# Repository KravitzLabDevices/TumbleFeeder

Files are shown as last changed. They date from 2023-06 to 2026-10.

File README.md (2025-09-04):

# TumbleFeeder
This is a feeding device for mice

## Front 


## Back

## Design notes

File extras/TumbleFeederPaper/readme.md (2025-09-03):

The paper using the TumbleFeeder, Barrett et al., Current Biology 2025 is [here](https://www.sciencedirect.com/science/article/pii/S0960982225006839?via%3Dihub)  

Example Code and Data Analysis pipelines are [available here](https://github.com/KravitzLab/Barrett2024/tree/main)

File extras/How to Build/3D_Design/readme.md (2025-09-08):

Print the 3D parts
[Download the four STLs here](https://github.com/KravitzLabDevices/TumbleFeeder/tree/main/How%20to%20Build/3D_Design).  We print in PLA plus with a Bambu Labs X1C, but the exact printer and material are not critical. If you don't have a printer you can even outsource the printing to companies like Shapeways. 
[Editable TinkerCAD file](https://www.tinkercad.com/things/1IhfIT78Xpz-tumble-feeder-sept2024) are here

{AB542B00-AB26-41CA-B7AA-14D2C4CE198B}

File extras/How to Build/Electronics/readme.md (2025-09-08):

# Electronics

First order the two custom PCBs.  You can order from OshPark using the link below, or order from any PCB house using the [Eagle .brd and .sch files](https://github.com/KravitzLabDevices/TumbleFeeder/tree/main/How%20to%20Build/Electronics).
1) The main PCB<br>
6047149a1ac6b429ac75a2f4fb032c3e

<br>
<br>
2) The small touch adapter PCB:  <br>
{D103E9D6-0BA7-4F27-A367-4E5D317DD4B2}  <br>  


Next order all the necessary parts, [the BOM is here](https://docs.google.com/spreadsheets/d/167cMoID8Alf8LLFngqACXI5k8x5zef9LXBQ9bw7NaI0/edit?gid=0#gid=0).  
To assemble the PCB, we recommend watching the [Tumble Feeder Build Video](https://www.youtube.com/watch?v=_t9MZKi8byM") (YouTube Link)

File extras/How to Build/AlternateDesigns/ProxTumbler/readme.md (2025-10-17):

### A variant of the TumbleFeeder that uses the [VL6180](https://www.adafruit.com/product/3316) prox sensor to detect the mouse and open the feeder.



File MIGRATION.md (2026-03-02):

# Migration Guide: Converting CastleCode to TumbleFeeder Library

This guide shows how to convert your existing CastleCode sketch to use the TumbleFeeder library.

## Step 1: Install the Library

Copy the `TumbleFeeder` folder to your Arduino libraries directory.

## Step 2: Update Your Main Sketch Header

### Before (a_header.h):
```cpp
//INCLUDE LIBRARIES
#include <Servo.h>
// ... other includes

/********************************************************
  Initialize variables
********************************************************/
unsigned long rightstart;
unsigned long leftstart;
int currentpos = 0;
int leftPokeCount = 0;
int rightPokeCount = 0;
int leftPokeDur = 0;
int rightPokeDur = 0;
int FeederCount = 0;
int leftFeederDur = 0;
int FR=1;
// ... other variables

/********************************************************
  Initialize servo
********************************************************/
Servo myservo;
```

### After:
```cpp
//INCLUDE LIBRARIES
#include <TumbleFeeder.h>  // Add this
#include <Servo.h>  // Keep if needed elsewhere
// ... other includes

/********************************************************
  Initialize TumbleFeeder
********************************************************/
TumbleFeeder feeder;

/********************************************************
  Keep other variables
********************************************************/
unsigned long menustart;
bool SessionStarted = false;
const unsigned long display_interval = 100;
unsigned long next_interval = 0;
unsigned long open_duration = 60;
int on_hour;
int off_hour;
bool mode = 0;
// ... other non-feeder variables
```

## Step 3: Update Setup() in Main Sketch

### Before (Startup.ino):
```cpp
void setup() {
  // ... RTC, SD, display setup
  
  pinMode(13, OUTPUT);
  // ... other pin setups
  
  attachInterrupt(digitalPinToInterrupt(A2), left_interrupt, FALLING);
  attachInterrupt(digitalPinToInterrupt(A0), right_interrupt, FALLING);
  attachInterrupt(digitalPinToInterrupt(A1), feed_interrupt, FALLING);
}
```

### After:
```cpp
void setup() {
  // ... RTC, SD, display setup (unchanged)
  
  // Initialize feeder
  feeder.begin(closedpos, openpos);  // Use your position values
  feeder.setFR(FR);
  feeder.setOpenDuration(open_duration);
  
  // Register callbacks
  feeder.setLogCallback(logData);
  feeder.setDisplayCallback(update_display);
  
  // Attach interrupts (same as before)
  attachInterrupt(digitalPinToInterrupt(A2), left_interrupt, FALLING);
  attachInterrupt(digitalPinToInterrupt(A0), right_interrupt, FALLING);
  attachInterrupt(digitalPinToInterrupt(A1), feed_interrupt, FALLING);
  
  // ... rest of setup
}
```

## Step 4: Update Interrupt Handlers

### Before (InterruptRoutines.ino):
```cpp
void left_interrupt() {
  left_touch = 1;
}

void right_interrupt() {
  right_touch = 1;
}

void feed_interrupt() {
  feed_touch = 1;
}
```

### After:
```cpp
void left_interrupt() {
  feeder.handleLeftTouch();
}

void right_interrupt() {
  feeder.handleRightTouch();
}

void feed_interrupt() {
  feeder.handleFeederTouch();
}
```

## Step 5: Replace Feeder Functions

### Delete or comment out MoveFeeder.ino
The library now handles all feeder movement. Delete these functions:
- `feeder_open()`
- `feeder_close()`
- `shake()`
- `shake_food()`

If you need them elsewhere, use:
```cpp
feeder.feederOpen();
feeder.feederClose();
feeder.shake();
feeder.shakeFood();
```

## Step 6: Update run() Function

### Before (run.ino):
```cpp
void run() {
  unsigned long current = millis();

  if (current >= next_interval && mode == 0) {
    check_inputs(closedpos, openpos, open_duration);  
    next_interval = current + display_interval;
  }

  else if (current >= next_interval && mode == 1) {
    free_inputs(closedpos, openpos);
    next_interval = current + display_interval;
    if (wake_counter % 180 == 0) {
      shake_food();
    }
  }
}
```

### After:
```cpp
void run() {
  unsigned long current = millis();

  if (current >= next_interval && mode == 0) {
    feeder.checkInputs(open_duration);  // Simplified!
    next_interval = current + display_interval;
  }

  else if (current >= next_interval && mode == 1) {
    feeder.freeInputs();  // Simplified!
    next_interval = current + display_interval;
    if (wake_counter % 180 == 0) {
      feeder.shakeFood();
    }
  }
}
```

## Step 7: Delete Checkinputs.ino

The library handles all input checking. Delete these functions:
- `check_inputs()`
- `checkLeft()`
- `checkRight()`
- `checkFeeder()`
- `free_inputs()`

## Step 8: Update Variable References

Anywhere you access feeder counters, you can use either:

### Option A: Direct access (backward compatible)
```cpp
// Works the same as before
if (feeder.leftPokeCount > 10) {
  // do something
}
```

### Option B: Getter methods (recommended)
```cpp
if (feeder.getLeftPokeCount() > 10) {
  // do something
}
```

## Step 9: Update Display.ino

### Before:
```cpp
void update_display() {
  display.setCursor(0, 0);
  display.print("L:");
  display.print(leftPokeCount);
  display.print(" R:");
  display.print(rightPokeCount);
  display.print(" F:");
  display.print(FeederCount);
  display.refresh();
}
```

### After:
```cpp
void update_display() {
  display.setCursor(0, 0);
  display.print("L:");
  display.print(feeder.leftPokeCount);  // or feeder.getLeftPokeCount()
  display.print(" R:");
  display.print(feeder.rightPokeCount);  // or feeder.getRightPokeCount()
  display.print(" F:");
  display.print(feeder.FeederCount);     // or feeder.getFeederCount()
  display.refresh();
}
```

## Step 10: Update LogData.ino

### Before:
```cpp
void logData() {
  logfile.print(millis());
  logfile.print(",");
  logfile.print(leftPokeCount);
  logfile.print(",");
  logfile.print(rightPokeCount);
  logfile.print(",");
  logfile.print(FeederCount);
  // ... etc
}
```

### After:
```cpp
void logData() {
  logfile.print(millis());
  logfile.print(",");
  logfile.print(feeder.leftPokeCount);
  logfile.print(",");
  logfile.print(feeder.rightPokeCount);
  logfile.print(",");
  logfile.print(feeder.FeederCount);
  // ... etc
}
```

## Complete Conversion Checklist

- [ ] Install TumbleFeeder library
- [ ] Add `#include <TumbleFeeder.h>` to header
- [ ] Create `TumbleFeeder feeder;` object
- [ ] Remove old feeder-related global variables
- [ ] Update `setup()` with `feeder.begin()` and callbacks
- [ ] Update interrupt handlers to call `feeder.handleXXX()`
- [ ] Delete/comment out MoveFeeder.ino
- [ ] Update `run()` to use `feeder.checkInputs()`
- [ ] Delete/comment out Checkinputs.ino
- [ ] Update all variable references to `feeder.variableName`
- [ ] Test on hardware!

## Benefits After Migration

✅ **Cleaner code**: Feeder logic is encapsulated  
✅ **Reusable**: Use the library across multiple projects  
✅ **Maintainable**: Bug fixes in one place  
✅ **Flexible**: Easy to swap between FR schedules  
✅ **Professional**: Standard Arduino library format  

## Troubleshooting

### "Feeder not responding"
- Check servo positions: `feeder.setPositions(0, 150)`
- Verify interrupts are attached correctly
- Check pin connections match hardcoded pins

### "Counts not incrementing"
- Ensure callbacks are registered: `feeder.setLogCallback(logData)`
- Check ISRs are calling `feeder.handleXXX()` methods
- Verify touch sensors are wired correctly (A2, A0, A1)

### "Compile errors"
- Make sure library is in Arduino libraries folder
- Restart Arduino IDE after installing library
- Check you removed duplicate function definitions

## Need Help?

Open an issue on GitHub with:
- Your error message
- Code snippet showing the problem
- What you've already tried

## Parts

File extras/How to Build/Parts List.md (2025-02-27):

## <a href="https://docs.google.com/spreadsheets/d/167cMoID8Alf8LLFngqACXI5k8x5zef9LXBQ9bw7NaI0/edit?usp=sharing" target="_blank" rel="noopener noreferrer">Click here</a> for TumbleFeeder parts list.
<br>
Updated 2/27/2025

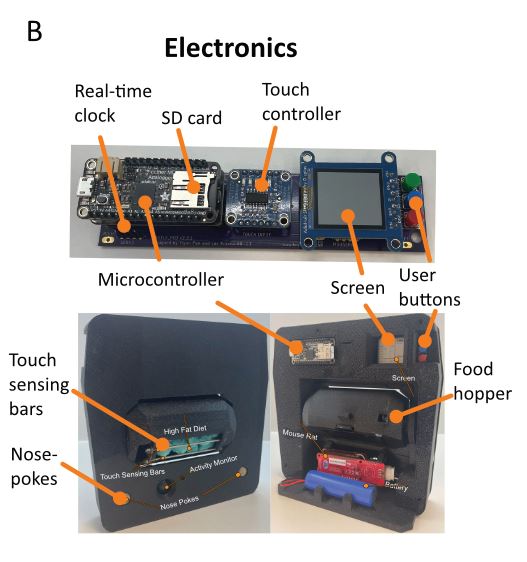
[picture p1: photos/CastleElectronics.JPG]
TumbleFeeder


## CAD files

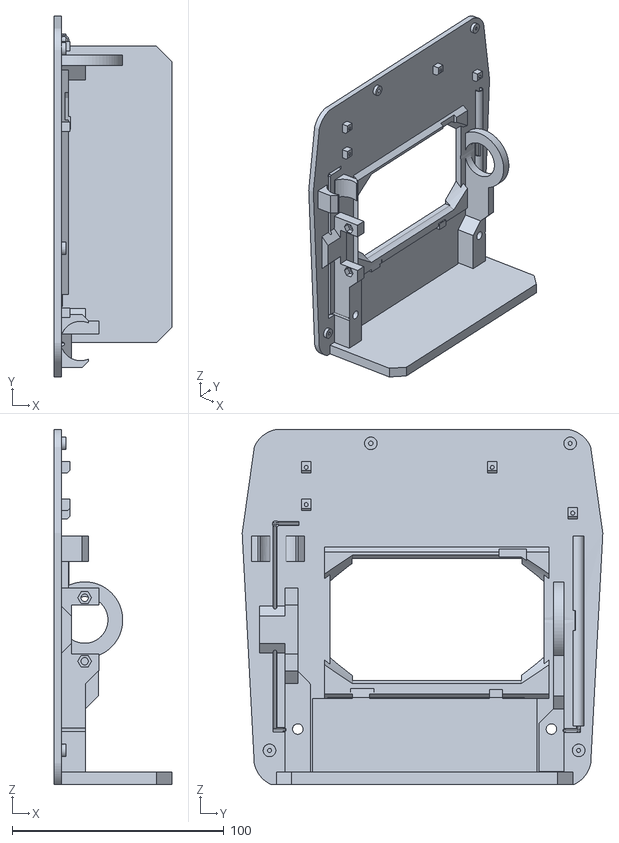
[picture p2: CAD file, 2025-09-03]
extras/How to Build/3D_Design/TumbleFeederFront.stl
55.5 x 170.3 x 167.6

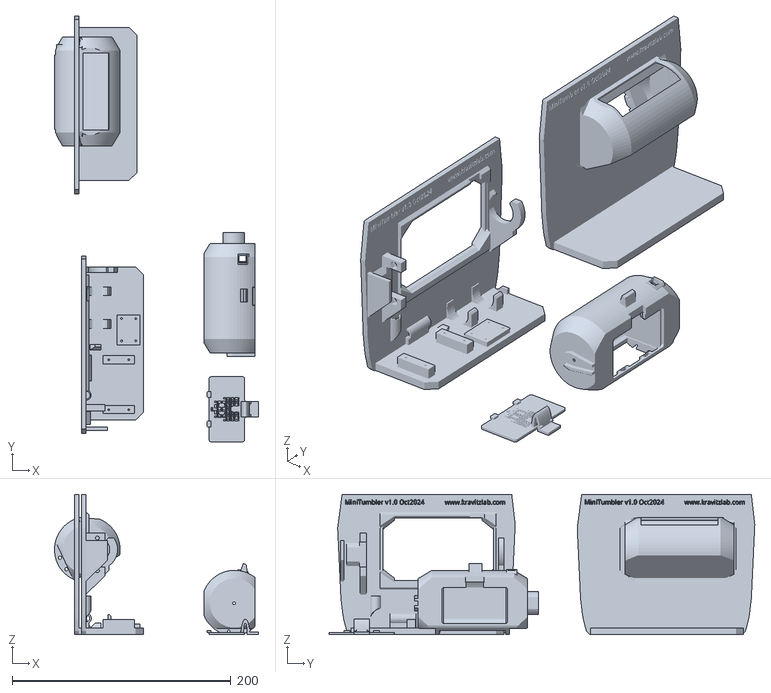
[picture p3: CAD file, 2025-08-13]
extras/How to Build/AlternateDesigns/MiniTumbler/How to build/3D files/Mini Tumbler August2025.stl
186.5 x 389.0 x 128.0

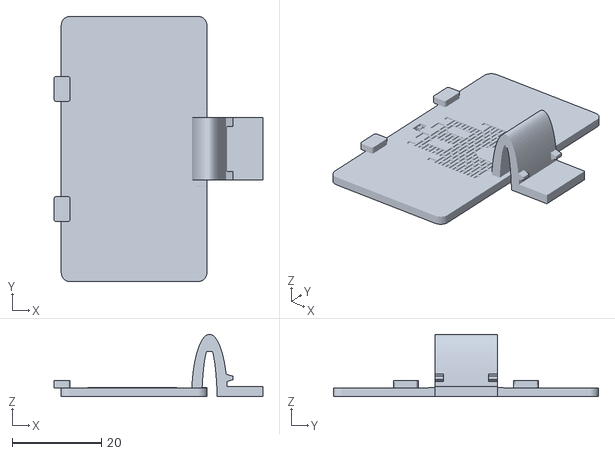
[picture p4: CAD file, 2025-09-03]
extras/How to Build/3D_Design/TumbleFeederDoor.stl
46.9 x 59.5 x 14.0

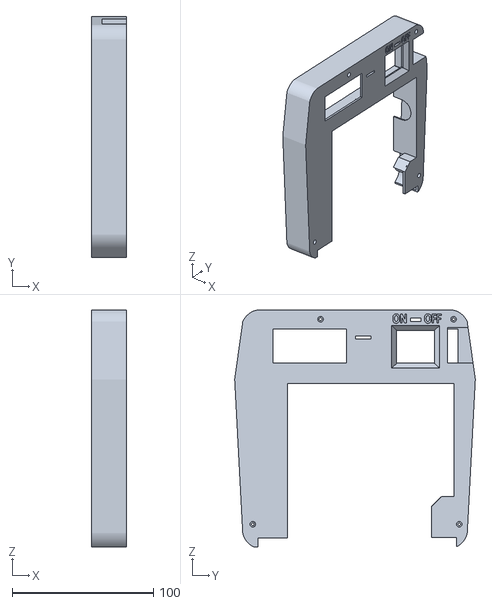
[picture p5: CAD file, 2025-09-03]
extras/How to Build/3D_Design/TumbleFeederBack.stl
25.0 x 170.2 x 167.6

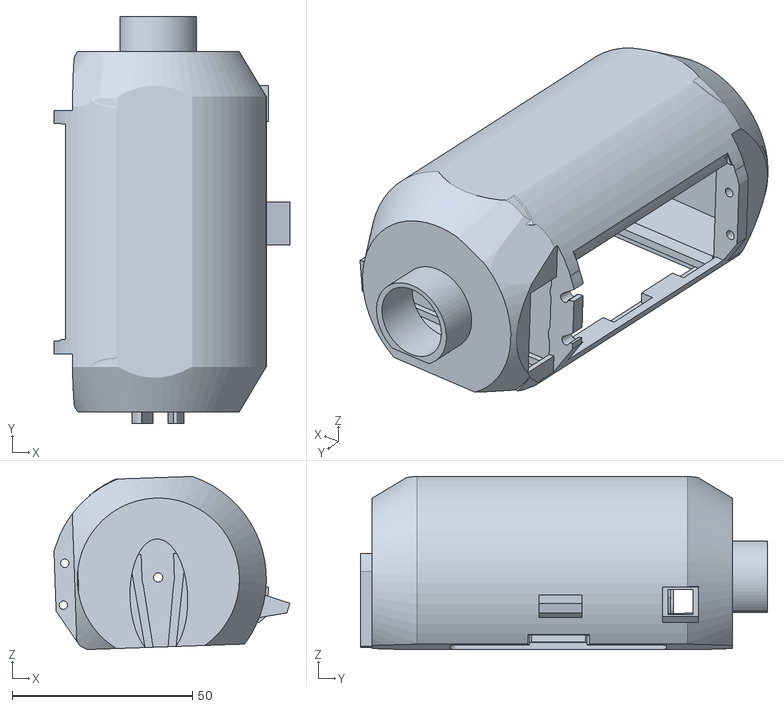
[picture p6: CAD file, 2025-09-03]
extras/How to Build/3D_Design/TumbleFeederHopper.stl
65.5 x 113.1 x 48.1

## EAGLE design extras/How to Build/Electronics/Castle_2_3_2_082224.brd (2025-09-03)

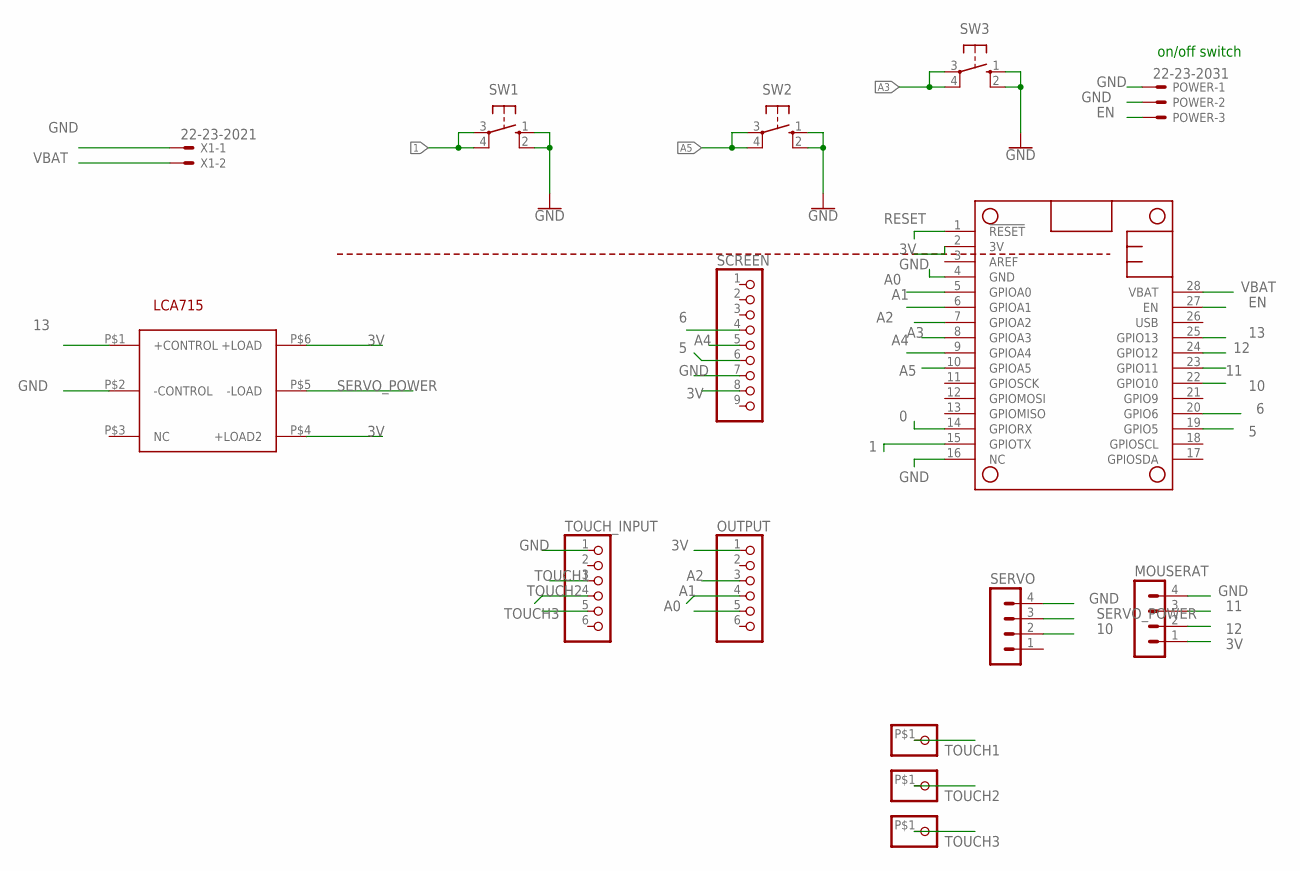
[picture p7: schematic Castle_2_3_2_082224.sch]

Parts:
EXTRAGND, EXTRAGND1, EXTRAGND2: PINHD-1X1-BIGPOGO; 1X1-BIGPOGO
LCA715: LCA715S; LCA7XX
MOUSERAT: MA04-1
MS2: FEATHERWING_NODIM; FEATHERWING_DIM
OUTPUT: PINHD-1X6; 1X06
POWER: 22-23-2031
SCREEN: PINHD-1X9; 1X09-BIG
SERVO: MA04-1
SW1, SW2, SW3: 10-XX; B3F-10XX
TOUCH_INPUT: PINHD-1X6; 1X06
X1: 22-23-2021

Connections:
0: MS2.14 (GPIORX)
1: MS2.15 (GPIOTX), SW1.3, SW1.4 (P1)
3V: LCA715.P$4 (+LOAD2), LCA715.P$6 (+LOAD), MOUSERAT.1, MS2.2 (3V), OUTPUT.1, SCREEN.8
5: MS2.19 (GPIO5), SCREEN.6
6: MS2.20 (GPIO6), SCREEN.4
10: MS2.22 (GPIO10), SERVO.2
11: MOUSERAT.3, MS2.23 (GPIO11)
12: MOUSERAT.2, MS2.24 (GPIO12)
13: LCA715.P$1 (+CONTROL), MS2.25 (GPIO13)
A0: MS2.5 (GPIOA0), OUTPUT.5
A1: MS2.6 (GPIOA1), OUTPUT.4
A2: MS2.7 (GPIOA2), OUTPUT.3
A3: MS2.8 (GPIOA3), SW3.3, SW3.4 (P1)
A4: MS2.9 (GPIOA4), SCREEN.5
A5: MS2.10 (GPIOA5), SW2.3, SW2.4 (P1)
EN: MS2.27 (EN), POWER.3
GND: LCA715.P$2 (-CONTROL), MOUSERAT.4, MS2.4 (GND), MS2.16 (NC), POWER.1, POWER.2, SCREEN.7, SERVO.4, SW1.1 (S), SW1.2 (S1), SW2.1 (S), SW2.2 (S1), SW3.1 (S), SW3.2 (S1), TOUCH_INPUT.1, X1.1
RESET: MS2.1 (!RESET)
SERVO_POWER: LCA715.P$5 (-LOAD), SERVO.3
TOUCH1: EXTRAGND.P$1, TOUCH_INPUT.3
TOUCH2: EXTRAGND1.P$1, TOUCH_INPUT.4
TOUCH3: EXTRAGND2.P$1, TOUCH_INPUT.5
VBAT: MS2.28 (VBAT), X1.2

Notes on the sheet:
on/off switch

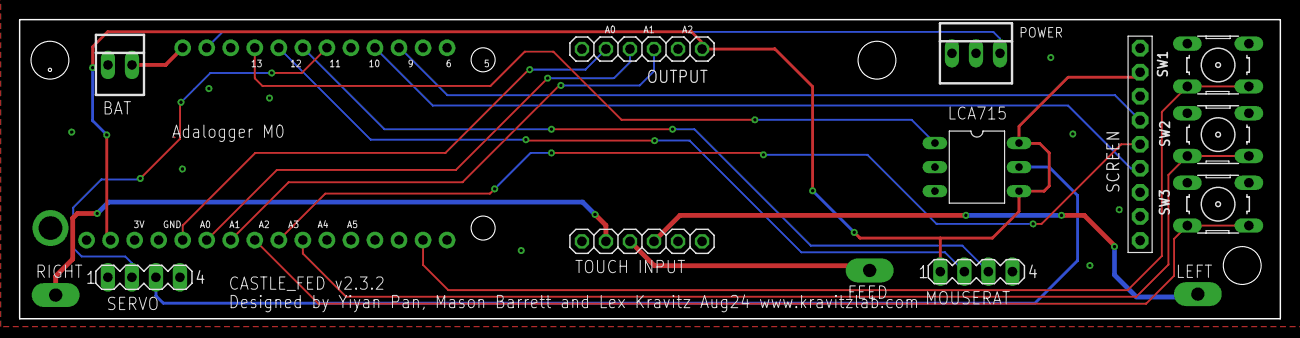
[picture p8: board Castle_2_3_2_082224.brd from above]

Board: 2 copper layers, 133.2 x 31.6 mm, 15 parts (0 on the bottom side), 21 nets.

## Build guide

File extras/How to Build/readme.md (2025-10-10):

# Build the TumbleFeeder

A fast, repeatable build you can complete with common tools and off-the-shelf parts.

**Quick links:**  
- ▶️ **[Build Video (YouTube)](https://www.youtube.com/watch?v=_t9MZKi8byM)**  
- 🧩 **[3D Parts (STL)](https://github.com/KravitzLabDevices/TumbleFeeder/tree/main/How%20to%20Build/3D_Design)**  
- ✏️ **[Editable TinkerCAD](https://www.tinkercad.com/things/1IhfIT78Xpz-tumble-feeder-sept2024)**  
- 🖥️ **[Electronics (Eagle .brd/.sch)](https://github.com/KravitzLabDevices/TumbleFeeder/tree/main/How%20to%20Build/Electronics)**  
- 📋 **[BOM (Google Sheet)](https://docs.google.com/spreadsheets/d/167cMoID8Alf8LLFngqACXI5k8x5zef9LXBQ9bw7NaI0/edit?gid=0#gid=0)**

---

## Build Steps

1. **3D print the four parts**  
2. **Populate the PCB(s)**  
3. **Assemble the TumbleFeeder**  
4. **Flash and test the device**

→ Prefer video? Watch the **[Build Video](https://www.youtube.com/watch?v=_t9MZKi8byM)**.

---

## 1) Print the 3D parts

Printed parts
  
- **Download STLs:**  
  https://github.com/KravitzLabDevices/TumbleFeeder/tree/main/How%20to%20Build/3D_Design  
- **Material/Printer:** PLA+ on a Bambu X1C works well (others are fine).  
- **No printer?** Services like Shapeways will work.  
- **Editable model:**  
  https://www.tinkercad.com/things/1IhfIT78Xpz-tumble-feeder-sept2024  

<sub><br clear="both"></sub>

---

## 2) Populate the PCB

Order the two custom PCBs (OSH Park badges below) or build from the Eagle files.

**Files:** https://github.com/KravitzLabDevices/TumbleFeeder/tree/main/How%20to%20Build/Electronics

**PCBs:**
1. **Main PCB**  
   Main PCB render  
   <a href="https://oshpark.com/shared_projects/G0He9rRP">
     
   </a>

2. **Touch adapter PCB**  
   Touch PCB  
   <a href="https://oshpark.com/shared_projects/q8TvJ7jU">
     
   </a>

**Parts:** See the **[BOM](https://docs.google.com/spreadsheets/d/167cMoID8Alf8LLFngqACXI5k8x5zef9LXBQ9bw7NaI0/edit?gid=0#gid=0)**.  
**Soldering walkthrough:** in the **[Build Video](https://www.youtube.com/watch?v=_t9MZKi8byM)**.

---

## 3) Assemble the TumbleFeeder

For a full assembly demo, watch the **[Build Video](https://youtu.be/_t9MZKi8byM?si=ihr77ZkaLHi7A_hr&t=212)**.

### Recommended order

1) **Solder headers on all PCBs and modules**

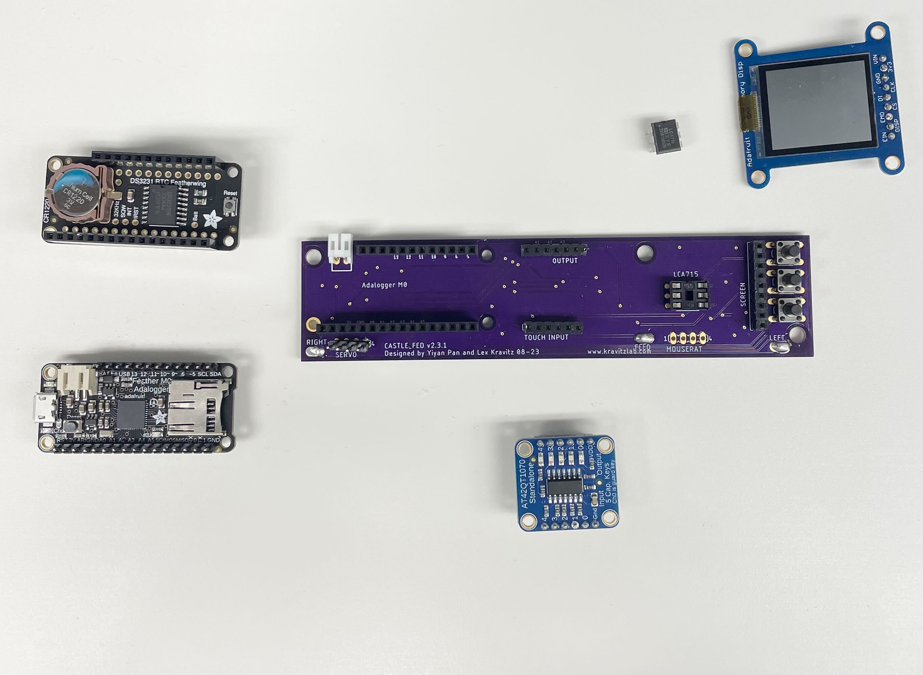
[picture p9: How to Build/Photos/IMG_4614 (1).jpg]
Header soldering


- Solder all pin headers onto the custom PCBs and each module.
- Keep pins vertical; use a breadboard or third-hand tool for alignment.

> **Note:** The **RTC board** is the only module that uses **stacking headers**.

<br clear="both" />

---

2) **Install modules onto the main PCB**

Assembly reference

- Seat each module on the header footprint matching its silkscreen.
- Double-check orientation and clearance before soldering.

---

3) **Assemble the tumbler (touch board + JST lead)**

Jump to **1:54** in the **[Build Video](https://youtu.be/_t9MZKi8byM?feature=shared&t=114)**.

Touch board wiring

- Solder the **JST-PH** connector to the **touch adapter board**.
- Plug a **2-pin JST lead** into the connector.
- Remove the unused cable on the connector.
- **Cable length tip:** If the red wire is too short, you can repurpose extra black lead as an **extension for the red line**. Use heat-shrink and solder the staggered splices.

<br clear="both" />

---

4) **Attach components to the 3D-printed body**

Jump to **3:32** in the **[Build Video](https://youtu.be/_t9MZKi8byM?si=ihr77ZkaLHi7A_hr&t=212)**.

Mounting into the printed body

- Dry-fit first to confirm cable routing and connector access.
- Mount the main PCB, touch board, and wiring harness; avoid pinching cables.
- Verify clearance for moving parts before final fasteners.

---

## 4) Flash and test

Jump to **7:19** in the **[Build Video](https://youtu.be/_t9MZKi8byM?feature=shared&t=469)** for flashing and validation.

### Required Arduino libraries
Libraries screenshot

The firmware expects the following libraries:

- **Servo — `Servo.h`** — Michael Margolis, Arduino  
- **Wire — `Wire.h`** — Included with *Arduino AVR Boards* (Boards Manager)  
- **RTClib — `RTClib.h`** — Adafruit  
- **Arduino Low Power — `ArduinoLowPower.h`** — Arduino  
- **SPI — `SPI.h`** — Included with *Adafruit SAMD Boards* (Boards Manager)  
- **SdFat — `SdFat.h`** — Bill Greiman  
- **Adafruit GFX — `Adafruit_GFX.h`** — Adafruit  
- **Time — `TimeLib.h`** — Michael Margolis  
- **FlashStorage — `FlashStorage.h`** — Various Authors  
- **Adafruit FreeTouch — `Adafruit_FreeTouch.h`** — Adafruit  
- **Adafruit SHARP Memory Display — `Adafruit_SharpMem.h`** — Adafruit

<br clear="both" />

---

### Toolchain setup (Boards Manager)

Boards Manager

1. **Add Adafruit’s Board Manager URL**  
   Arduino IDE → **File → Preferences → Additional Boards Manager URLs** → add: "https://adafruit.github.io/arduino-board-index/package_adafruit_index.json"
2. **Install board package**  
**Tools → Board → Boards Manager…** → search “Adafruit SAMD” → **Install**.
3. **Select your board and port**  
**Tools → Board** → choose your *Adafruit Feather M0* (or the specific SAMD board).  
**Tools → Port** → choose the corresponding COM/tty device.

---

### Flash the firmware

1. Open the sketch in Arduino IDE.
2. Plug your board into your computer via a micro USB cable and double-tap the reset button on the board.
3. Verify the correct **Board** and **Port** (see above).  
4. Click **Upload**. For first-time flashing or if the upload fails, double-tap reset to enter bootloader mode and upload again.

---

### Set the RTC (DS3231)

To initialize the clock, load **File → Examples → RTClib → ds3231** and upload. This sets the RTC using the sketch’s compile time.  



- On Feather M0/SAMD boards, ensure the correct board package is installed and the right COM port is selected.
- If flashing fails mid-way, double-tap reset to enter bootloader mode and retry upload.

<br clear="both" />

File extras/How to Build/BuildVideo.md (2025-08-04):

## <a href="https://www.youtube.com/watch?v=_t9MZKi8byM" target="_blank" rel="noopener noreferrer">Click here</a> for Tumble Feeder Build Video.
<br>
Updated 8/4/2025

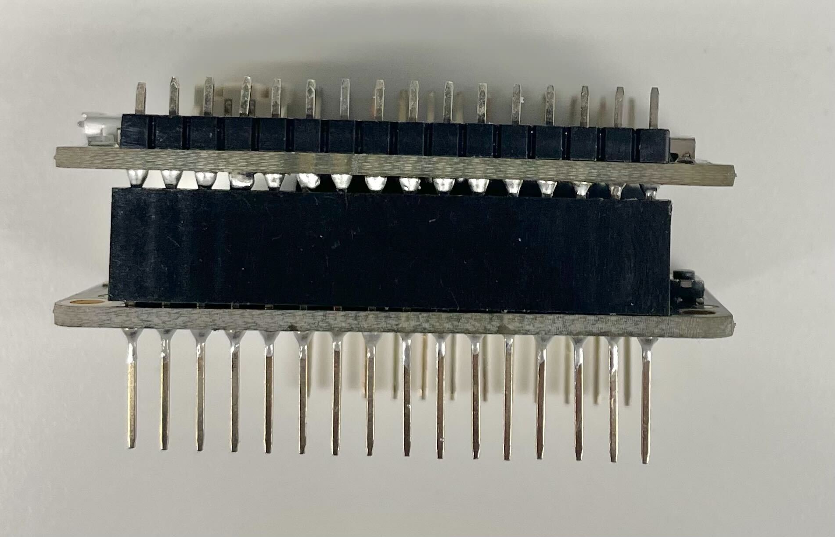
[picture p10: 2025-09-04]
extras/How to Build/Photos/IMG_4616 (1).jpg

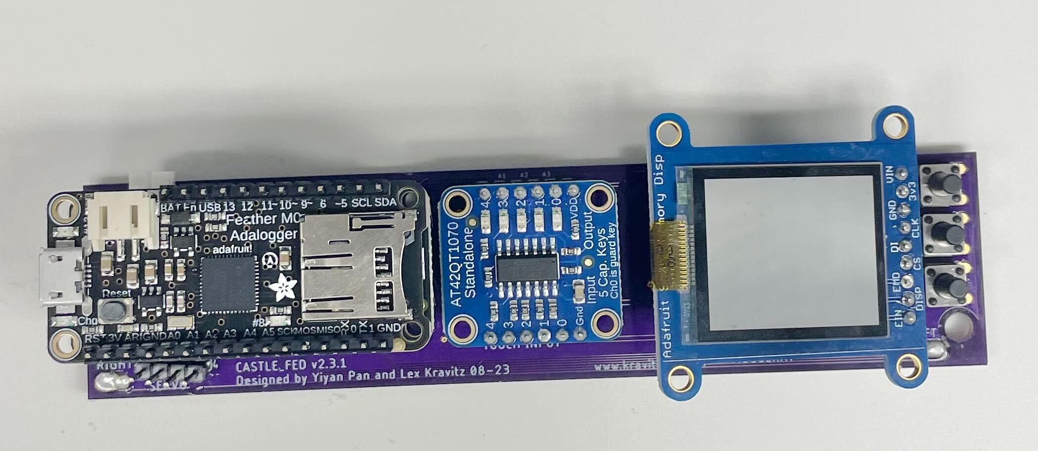
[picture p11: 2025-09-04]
extras/How to Build/Photos/IMG_4618 (1).jpg

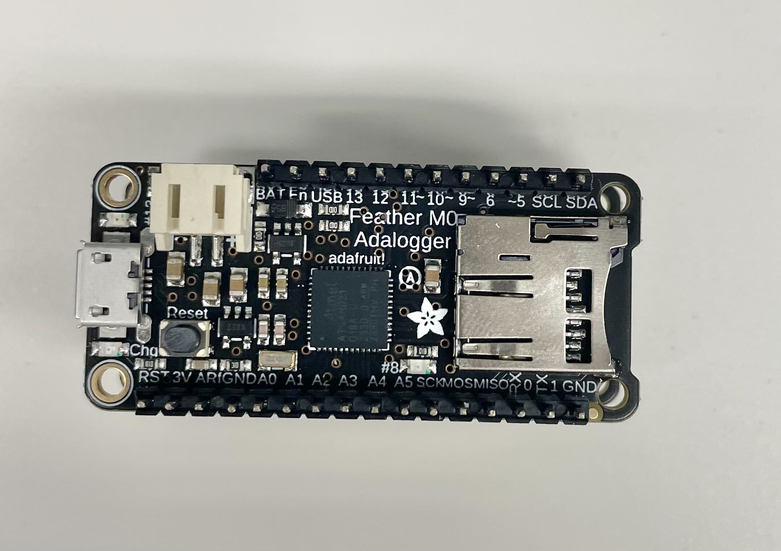
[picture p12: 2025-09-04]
extras/How to Build/Photos/IMG_4617 (1).jpg

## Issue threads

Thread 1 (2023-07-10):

Think about how to stop detecting touches during shake()

KravitzLab, 2023-07-10:
Sometimes shake() triggers the touch sensor.  We subtract 1 from LeftFeedCount to compensate for this but we should come up with a more robust solution.

KravitzLab, 2023-09-13:
This is also triggering a touch on the MouseRat devices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

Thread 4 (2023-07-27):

Shake function adds one to feedcount

jordynczarny, 2023-07-27:
YY's solution was to subtract 1 from leftFeederCount each time shake is called.  We should revisit if there's a better way to do this because this results in a duplicate line in the logfile as leftFeederCount is logged, then shake happens and subtracts 1, and then it logs again.

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

MasBarr, 2023-11-16:
Holding A1 LOW while we shake seems to solve it - needs more testing
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

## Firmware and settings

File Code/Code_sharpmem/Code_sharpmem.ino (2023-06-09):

/* Castle Fed
  by Lex Kravitz & Yiyan Pan
  Last Modified April 12th, 2023
*/

/********************************************************
  Setup code
********************************************************/
#include "a_header.h" //See "a_Header.h" for #defines and other constants 
bool toggle = false;
const unsigned long display_interval = 100;
unsigned long next_interval = 0;
int middlepos ;
int leftpos ;

int fromsd;
int CSL;
int count_pos = 0; // 0 initialize count_pos here for switching between l,r,m using %

int left_touch;
int right_touch;
int start_touch;
int feed_touch;
boolean buttonLow = false;
boolean freefeed;
int analog_pos;
int *pt_middle = &analog_pos;
unsigned int wake_counter = 0;
/*****************************************************************
     Set up screen
 *****************************************************************/

void setup() {
  Serial.begin(9600);
  startup();
  display.begin();
  display.clearDisplay();

}

int margin = 10;
void loop() {
  while (!toggle) {
    calibrate_servo();
  }
  doWork();
  LowPower.sleep(5000);
  wake_counter++;

}

void left_interrupt() {
  left_touch = 1;
}

void right_interrupt() {
  right_touch = 1;
}

void feed_interrupt() {
  feed_touch = 1;
}

void interrupt() {
  //
}


/********************************************************
  check for user button touch and start the device
********************************************************/
void doWork() {
  unsigned long current = millis();
  if (current >= next_interval && freefeed == false) {
    check_inputs(middlepos, leftpos); // put in all three position
    next_interval = current + display_interval;
    count_pos = 0;
  }
  else if (current >= next_interval && freefeed == true) {
    if (wake_counter % 180 == 0) {
      move_center(middlepos);
      move_left(leftpos);
      //leftFeederCount--;
      logData();
    }
    free_inputs(middlepos, leftpos);
    next_interval = current + display_interval;
    count_pos = 0;
  }

}

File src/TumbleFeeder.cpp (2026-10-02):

/*
  TumbleFeeder.cpp - Comprehensive library for servo-based pellet feeder
*/

#include "Arduino.h"
#include "TumbleFeeder.h"

// Static member initialization
TumbleFeeder* TumbleFeeder::_instance = nullptr;

/**************************************************************************************************************************************************
                                                                                    Constructor and Initialization
**************************************************************************************************************************************************/

// Constructor
TumbleFeeder::TumbleFeeder() {
  // Initialize counters
  leftPokeCount = 0;
  rightPokeCount = 0;
  FeederCount = 0;
  proxOpenCount = 0;
  leftPokeDur = 0;
  rightPokeDur = 0;
  leftFeederDur = 0;
  
  // Initialize touch flags
  _leftTouch = false;
  _rightTouch = false;
  _feedTouch = false;
  
  // Default configuration
  FR = 1;
  proxDuration = 3;
  mode = 0;  // FR mode
  deviceNumber = 0;
  closedpos = 150;
  openpos = 0;
  open_duration = 60;

  // Proximity lockout state
  _requireClear = false;
  _lastFeedEnd = 0;
  _awayStart = 0;

  // Session state
  _SessionStarted = false;
  _sdAvailable = false;
  _fileCreated = false;
  memset(filename, 0, sizeof(filename));
  _endstate = false;
  _wake_counter = 0;
  _EnableSleep = true;
  
  // Set instance pointer for static ISRs
  _instance = this;
}

// Main initialization
void TumbleFeeder::begin() {
  Serial.begin(9600);

  pinMode(BNC_PIN, OUTPUT);
  digitalWrite(BNC_PIN, LOW);

  /********************************************************
    Initialize pins
  ********************************************************/
  pinMode(LED_PIN, OUTPUT);
  pinMode(LEFT_TOUCH_PIN, INPUT_PULLUP);
  pinMode(RIGHT_TOUCH_PIN, INPUT_PULLUP);
  pinMode(FEEDER_TOUCH_PIN, INPUT_PULLUP);
  pinMode(RED_BUTTON, INPUT_PULLUP);
  pinMode(GREEN_BUTTON, INPUT_PULLUP);
  pinMode(BLUE_BUTTON, INPUT_PULLUP);
  pinMode(VBATPIN, INPUT);
  
  digitalWrite(LED_PIN, LOW);
  
  /********************************************************
    Initialize RTC
  ********************************************************/
  rtc.begin();
  
  /********************************************************
    Initialize Display
  ********************************************************/
  display.begin();
  display.setTextSize(1);
  display.setTextColor(BLACK);
  display.setRotation(1);
  display.fillRect(0, 0, 168, 144, WHITE);
  display.refresh();
  
  /********************************************************
    Initialize SD Card
  ********************************************************/
  SdFile::dateTimeCallback(_dateTime);
  _initSD();
  _createPos();  // Load saved positions and settings
  
  /********************************************************
    Initialize Proximity Sensor (always — needed if mode 4 is selected via menu)
  ********************************************************/
  Wire.begin();
  _vl.begin();

  /********************************************************
    Attach Interrupts
  ********************************************************/
  LowPower.attachInterruptWakeup(digitalPinToInterrupt(LEFT_TOUCH_PIN), _leftISR, FALLING);
  LowPower.attachInterruptWakeup(digitalPinToInterrupt(RIGHT_TOUCH_PIN), _rightISR, FALLING);
  LowPower.attachInterruptWakeup(digitalPinToInterrupt(FEEDER_TOUCH_PIN), _feedISR, FALLING);
  LowPower.attachInterruptWakeup(digitalPinToInterrupt(RED_BUTTON), _wakeISR, CHANGE);
  
  /********************************************************
    Startup Menu
  ********************************************************/
  while (!_SessionStarted) {
    _displayCurrentParams();
  }
  
  // Display is already showing run screen from _displayCurrentParams
  // No need to clear it
  
  Serial.println("TumbleFeeder initialized!");
}

/**************************************************************************************************************************************************
                                                                                    Main Run Loop
**************************************************************************************************************************************************/

void TumbleFeeder::run() {
  // This is called every loop - handles all input checking, display updates, and sleep
  unsigned long current = millis();
  
  // Check inputs at regular intervals
  if (current >= _next_interval) {
    if (mode == 0) {
      // FR mode
      _checkInputs();
    }
    else if (mode == 1) {
      // Free feeding mode
      _freeInputs();
      if (_wake_counter % 180 == 0 && !bncEnabled) {
        shakeFood();
      }
    }
    else if (mode == 2) {
      // FR Extend mode
      _checkInputs();
    }
    else if (mode == 3) {
      // Free Terminate mode
      _freeTerminateInputs();
      if (_wake_counter % 180 == 0 && !bncEnabled) {
        shakeFood();
      }
    }
    else if (mode == 4) {
      // Proximity mode
      _proxInputs();
    }
    
    _next_interval = current + _display_interval;
  }
  
  // Update display
  _updateDisplay();
  
  // Sleep management
  _goToSleep();
  
  _wake_counter++;
}

/**************************************************************************************************************************************************
                                                                                    Static Interrupt Handlers
**************************************************************************************************************************************************/

void TumbleFeeder::_leftISR() {
  if (_instance) {
    _instance->_handleLeftTouch();
  }
}

void TumbleFeeder::_rightISR() {
  if (_instance) {
    _instance->_handleRightTouch();
  }
}

void TumbleFeeder::_feedISR() {
  if (_instance) {
    _instance->_handleFeederTouch();
  }
}

void TumbleFeeder::_wakeISR() {
  // Just wake up - no action needed
}

/**************************************************************************************************************************************************
                                                                                    Touch Handlers
**************************************************************************************************************************************************/

void TumbleFeeder::_handleLeftTouch() {
  _leftTouch = true;
  if (bncEnabled && _SessionStarted && (bncMode == 1 || bncMode == 4)) {
    digitalWrite(BNC_PIN, HIGH);
    _bncStart = millis();
  }
}

void TumbleFeeder::_handleRightTouch() {
  _rightTouch = true;
  if (bncEnabled && _SessionStarted && (bncMode == 2 || bncMode == 4)) {
    digitalWrite(BNC_PIN, HIGH);
    _bncStart = millis();
  }
}

void TumbleFeeder::_handleFeederTouch() {
  _feedTouch = true;
  if (bncEnabled && _SessionStarted && (bncMode == 3 || bncMode == 4)) {
    digitalWrite(BNC_PIN, HIGH);
    _bncStart = millis();
  }
}
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

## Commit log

2023-01-11 need to fix screen
    [Checkinputs.ino, Code_sharpmem.ino, Display.ino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]
2023-01-13 added lowpower wakeup. works perfectly. need to test power consumption
2023-01-27 MOSFET ON PIN 11
    power consumption under sleep mode ~ 0.58 mA
2023-06-23 button left right updated
2023-08-17 Uploaded YY data
    [CASTLE_000_071723_07_.CSV, CASTLE_000_071823_05_.CSV, CASTLE_000_071823_18_.CSV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]
2023-10-12 More Example Data
    [CASTLE_000_061023_06_.CSV, CASTLE_000_071723_07_.CSV, CASTLE_000_071823_05_.CSV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]
2023-11-16 Fixed bug related to FR1 vs Free
    [Checkinputs.ino, Display.ino, InterruptRoutines.ino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]
2024-01-30 Shake and Low Power
    Got ride of shake subtraction and restarted low power mode
2024-02-01 updated electronics
    [Castle_2_2_2_060623.brd, Castle_2_2_2_060623.sch, Castle_2_3_1_103113.brd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]
2024-11-15 Added Device number to CSV and fixed blank file bug
    [LogData.ino]
2024-11-21 Fixed issue where touch durations were not being recorded
    [Checkinputs.ino, run.ino]
2025-08-04 Uploaded how to build video
    [CastleFeederHousing.stl, CastleFeederInsert.stl, Castle_2_2_2_060623.brd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]
2025-08-13 MiniTumbler 3D file
    [Mini Tumbler August2025.stl]
2025-09-03 Updated STLs
    [CastleFeederHousing.stl, CastleFeederInsert.stl, TumbleFeederBack.stl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]
2025-09-03 Restructure and relocate project files
    Moved code, 3D files, and electronics design files into a new organized directory structure under 'How to Build', including AlternateDesigns, OldVersions, and TumblerFeederCode. Deleted CastleCodev2.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
    [Castle_2_3_1_103113.brd, Castle_2_3_1_103113.sch, Castle_2_3_2_082224.brd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]
2025-09-03 Reorg exampleData
    [CASTLE_000_061023_06_.CSV, CASTLE_000_071723_07_.CSV, CASTLE_000_090723_01_.CSV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]
2025-10-16 Integrate VL6180X proximity sensor for feeder detection
    Added VL6180X sensor initialization and reading logic to detect proximity of mice to the feeder. Introduced checkProx.ino to handle sensor readings and set left_touch accordingly. Updated main loop t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
2025-10-17 Refactor for proximity-based feeder mode and UI updates
    Reworked input checking logic to support proximity-based (Prox) mode, removing right poke checks and simplifying left poke handling. Updated display labels from 'FR' to 'Prox' and 'ProxTime' for clarity. Enhanced proximity sensor logic to detect mouse presence and absence, and adjusted run loop to better separate Prox and Free modes.
    [Checkinputs.ino, Display.ino, checkProx.ino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]
2025-10-17 Refactor input logic to use proximity detection
    Replaces left/right touch logic with mouse proximity detection throughout the codebase. Updates variable names, display output, and data logging to reflect 'Approach' and 'Feed' events. Removes unused interrupt routines and touch variables, and adds a timeout function for feeder operation.
    [Checkinputs.ino, Display.ino, InterruptRoutines.ino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]
2025-10-17 Add detailed comments and improve UI in feeder code
    Extensive documentation and comments were added to Checkinputs.ino and Display.ino, clarifying input handling, feeding logic, and user interface flow. The display menus now include more descriptive l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
2025-10-17 Rename FeederCount to OpenCount throughout codebase
    Replaces all instances of the FeederCount variable with OpenCount for clarity and consistency in event tracking. Updates variable usage, display output, CSV logging, and documentation comments to reflect the new naming convention.
    [Checkinputs.ino, Display.ino, LogData.ino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]
2026-03-02 Edited library format
    [Castle_2_2_2_060623.brd, Castle_2_2_2_060623.sch, Castle_2_3_1_103113.brd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]
2026-04-07 Fixed flashing timer on FreeTerm
    [TumbleFeeder.cpp]
2026-04-17 Fixed naming error from "2_"
    [ClassicTumbleFeeder.ino, ProximityFeeding.ino, SetClock.ino]
2026-09-22 Fix shake frequency bug with BNC enabled; hide open duration in free modes
    Fixed a bug where the feeder would rapidly open and close every ~18 seconds in free feeding modes (Free and Free Terminate) when BNC output was enabled. BNC mode disables sleep, causing the wake counter to increment much faster than expected and triggering shakeFood() far too frequently. Shake is now disabled entirely when BNC is on.
    "Sec open" setting is no longer shown on the settings screen or in the edit menu when in Free or Free Terminate modes, since open duration is not used in those modes.
    [TumbleFeeder.cpp]

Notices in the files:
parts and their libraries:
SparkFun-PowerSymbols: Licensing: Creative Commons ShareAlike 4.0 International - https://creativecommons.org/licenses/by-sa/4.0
